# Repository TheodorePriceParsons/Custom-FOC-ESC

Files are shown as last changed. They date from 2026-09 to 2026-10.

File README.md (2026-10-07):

# Custom FOC ESC

Custom field-oriented-control motor controller.

## Structure
- `firmware/` — STM32G474 firmware (STM32CubeIDE project)
- `hardware/` — KiCad PCB design
- `mechanical/` — mounts and enclosure CAD

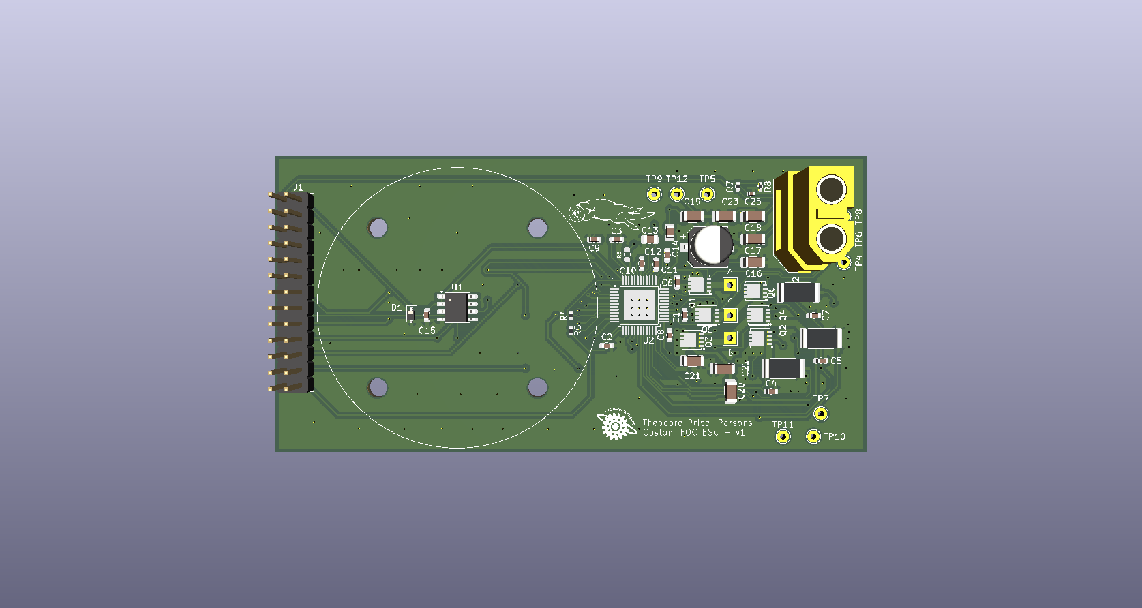
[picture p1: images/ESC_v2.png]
FOC ESC v2 — 3D render


### 1. Electrical angle

The MT6701 measures the mechanical angle $\theta_m$. The control math uses the electrical angle, which advances $p$ (number of pole pairs) times per mechanical revolution:

```math
\theta_e = p \, (\theta_m - \theta_0) \bmod 2\pi
```

$\theta_0$ is the encoder offset, found by running current through phase A and reading where the rotor settles.

### 2. Clarke transform: $(a, b, c) \rightarrow (\alpha, \beta)$

The three phase currents are 120° apart and sum to zero ($i_a + i_b + i_c = 0$), so only two of them carry independent information. The Clarke transform projects them onto two orthogonal stationary axes. The amplitude-invariant form keeps a phase current of amplitude $I$ as a vector of magnitude $I$:

```math
\begin{bmatrix} i_\alpha \\ i_\beta \end{bmatrix}
= \frac{2}{3}
\begin{bmatrix} 1 & -\tfrac{1}{2} & -\tfrac{1}{2} \\[2pt] 0 & \tfrac{\sqrt{3}}{2} & -\tfrac{\sqrt{3}}{2} \end{bmatrix}
\begin{bmatrix} i_a \\ i_b \\ i_c \end{bmatrix}
```

All three phase currents are used, in order to average shunt measurement noise.

### 3. Park transform: $(\alpha, \beta) \rightarrow (d, q)$

Rotating by $\theta_e$ moves into the rotor's reference frame. In steady state, the sinusoidal currents become **constants**:

```math
\begin{bmatrix} i_d \\ i_q \end{bmatrix}
=
\begin{bmatrix} \cos\theta_e & \sin\theta_e \\ -\sin\theta_e & \cos\theta_e \end{bmatrix}
\begin{bmatrix} i_\alpha \\ i_\beta \end{bmatrix}
```

- $i_d$: current aligned with the rotor magnets. It produces no torque and is regulated to 0.
- $i_q$: current perpendicular to the rotor magnets. Torque is $\tau = k_t i_q$.

The inverse Park transform is the transpose of the same rotation matrix:

```math
\begin{bmatrix} v_\alpha \\ v_\beta \end{bmatrix}
=
\begin{bmatrix} \cos\theta_e & -\sin\theta_e \\ \sin\theta_e & \cos\theta_e \end{bmatrix}
\begin{bmatrix} v_d \\ v_q \end{bmatrix}
```

### 4. Plant model

In the rotor frame, each axis is an RL circuit with coupling and back-EMF terms ($\omega_e$ = electrical speed, $\lambda$ = magnet flux linkage):

```math
v_d = R \, i_d + L \frac{di_d}{dt} - \omega_e L \, i_q
```

```math
v_q = R \, i_q + L \frac{di_q}{dt} + \omega_e L \, i_d + \omega_e \lambda
```

The $\omega_e$ terms vary slowly compared to the current loop, so they are treated as disturbances that the integrator rejects. Taking the Laplace transform with zero initial conditions gives the plant for each axis:

```math
G(s) = \frac{I(s)}{V(s)} = \frac{1}{Ls + R}
```

This is a single real pole at $s = -R/L$, i.e. the electrical time constant $\tau_e = L/R$.

### 5. PI current controller (continuous design)

```math
C(s) = K_p + \frac{K_i}{s} = K_p \, \frac{s + K_i/K_p}{s}
```

The open-loop transfer function is

```math
C(s) \, G(s) = \frac{K_p}{L} \cdot \frac{s + K_i/K_p}{s \, (s + R/L)}
```

Choose $K_i / K_p = R/L$ so that the controller zero cancels the plant pole (pole-zero cancellation, also called IMC tuning):

```math
C(s) \, G(s) = \frac{K_p}{L \, s}
\quad\Longrightarrow\quad
T(s) = \frac{C G}{1 + C G} = \frac{\omega_c}{s + \omega_c}, \qquad \omega_c = \frac{K_p}{L}
```

The closed loop is first-order with bandwidth $\omega_c$, so a step in the current reference produces no overshoot:

```math
i(t) = i_{ref} \left(1 - e^{-\omega_c t}\right)
```

```math
\boxed{K_p = \omega_c L, \qquad K_i = \omega_c R}
```

By the final value theorem, the integrator drives steady-state error to zero for a constant reference. This is why the control is done in the dq frame, where the references are DC.

**Choosing $\omega_c$.** The bandwidth must stay well below the loop rate $f_s$. A typical choice is $f_c \le f_s / 20$. If $R$ or $L$ is mismatched, the cancellation is imperfect, which causes mild overshoot or a slow tail. The loop stays stable for any positive gains.

**Measuring $L$.** Apply a voltage step $V$ to one phase pair. Taking the inverse Laplace transform of $V / (s(Ls+R))$ gives

```math
i(t) = \frac{V}{R} \left(1 - e^{-tR/L}\right)
```

so the time to reach 63.2% of the final current is $\tau_e = L/R$.

### 6. Discrete PI with anti-windup

The controller runs at a fixed period $T_s$. The integrator $1/s$ is discretized with forward Euler, $1/s \approx T_s/(z - 1)$:

```math
e[k] = i_{ref}[k] - i[k]
```

```math
v[k] = K_p \, e[k] + x[k]
```

```math
x[k+1] = x[k] + K_i T_s \, e[k]
```

The output voltage vector is limited by what the inverter can produce (see §7):

```math
\sqrt{v_d^2 + v_q^2} \le V_{max} = k_{max} \, \frac{V_{bus}}{\sqrt{3}}, \qquad k_{max} \approx 0.9
```

When the output saturates, the integrator update is skipped (conditional integration). This prevents windup at high speed, where back-EMF consumes the available voltage.

### 7. Space-vector modulation

The motor's star point floats, so it only responds to **differences** between phase voltages. Adding the same common-mode offset $v_{cm}$ to all three phases changes nothing the motor sees, but it can re-center the duties to use the full bus.

With inverse Clarke:

```math
v_a = v_\alpha, \qquad
v_b = -\tfrac{1}{2} v_\alpha + \tfrac{\sqrt{3}}{2} v_\beta, \qquad
v_c = -\tfrac{1}{2} v_\alpha - \tfrac{\sqrt{3}}{2} v_\beta
```

the common-mode offset is

```math
v_{cm} = \frac{\max(v_a, v_b, v_c) + \min(v_a, v_b, v_c)}{2}
```

and the duty for each phase $x \in$ {a, b, c} is

```math
d_x = \frac{1}{2} + \frac{v_x - v_{cm}}{V_{bus}}
```

This min/max injection is mathematically equivalent to symmetric (7-segment) SVPWM. It raises the maximum line-to-line voltage from $\sqrt{3}/2 \cdot V_{bus}$ (sine PWM) to $V_{bus}$, about 15.5% more, so the maximum phase-vector magnitude is $V_{bus}/\sqrt{3}$.

$k_{max} < 1$ keeps every phase low for part of each period, so the low-side shunt current can be sampled at the PWM center.

### 8. Parameters

| Symbol | Meaning | Value |
|---|---|---|
| $R$ | Phase resistance | TBD (measured) |
| $L$ | Phase inductance | TBD (step test) |
| $p$ | Pole pairs | TBD (count magnets / 2) |
| $\theta_0$ | Encoder offset | Calibrated at startup |
| $f_s$ | Control loop rate | ≈ 10.38 kHz |
| $f_c$ | Current loop bandwidth | TBD (≤ $f_s/20$) |
| $k_{max}$ | Modulation limit | 0.9 |

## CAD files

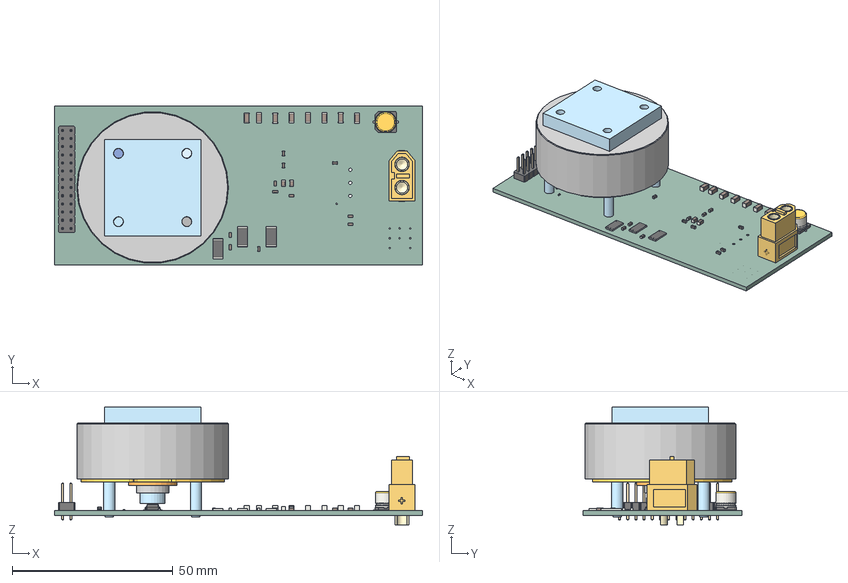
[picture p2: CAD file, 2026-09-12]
mechanical/Mounts.step
114.3 x 49.5 x 36.6 mm
Stator__Línea de partición1[12]
Stator__Línea de partición1[24]
Stator__Línea de partición1[1]
Rotor__Saliente-Extruir3[1]
Bearing__Simetría1
Stator__Línea de partición1[19]
Stator__Línea de partición1[4]
Rotor__Saliente-Extruir3[15]
Rotor__Rosca5
Stator__Línea de partición1[22]
Rotor__Saliente-Extruir3[16]
Nut__Cortar-Extruir1
Rotor__Saliente-Extruir3[6]
Rotor__Saliente-Extruir3[8]
Stator__Línea de partición1[17]
Rotor__Saliente-Extruir3[12]
Stator__Línea de partición1[14]
Stator__Línea de partición1[6]
Rotor__Saliente-Extruir3[21]
Rotor__Saliente-Extruir3[9]
Stator__Línea de partición1[7]
Stator__Línea de partición1[15]
Rotor__Saliente-Extruir3[14]
Rotor__Saliente-Extruir3[13]
Rotor__Saliente-Extruir3[2]
Rotor__Saliente-Extruir3[11]
Rotor__Saliente-Extruir3[5]
Stator__Redondeo5
Stator__Saliente-Extruir5
Stator__Línea de partición1[20]
Rotor__Saliente-Extruir3[20]
Stator__Línea de partición1[8]
Stator__Línea de partición1[10]
Rotor__Saliente-Extruir3[7]
Rotor__Saliente-Extruir3[19]
Stator__Línea de partición1[3]
Stator__Línea de partición1[9]
Rotor__Saliente-Extruir3[17]
Stator__Línea de partición1[11]
Stator__Línea de partición1[18]
Stator__Línea de partición1[16]
Rotor__Saliente-Extruir3[22]
Stator__Línea de partición1[5]
Stator__Línea de partición1[2]
Stator__Línea de partición1[23]
Rotor__Saliente-Extruir3[4]
Rotor__Saliente-Extruir3[10]
Rotor__Saliente-Extruir3[3]
Stator__Línea de partición1[13]
Rotor__Saliente-Extruir3[18]
Stator__Línea de partición1[21]
C_0603_1608Metric x 13
C_0805_2012Metric x 2
C_1206_3216Metric x 8
R_0402_1005Metric x 2
PinHeader_2x13_P254mm_Vertical
SO-8_3.9x4.9mm_P1.27mm
D_SOD-323
R_2512_6332Metric x 3
ESCC85C_PCB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

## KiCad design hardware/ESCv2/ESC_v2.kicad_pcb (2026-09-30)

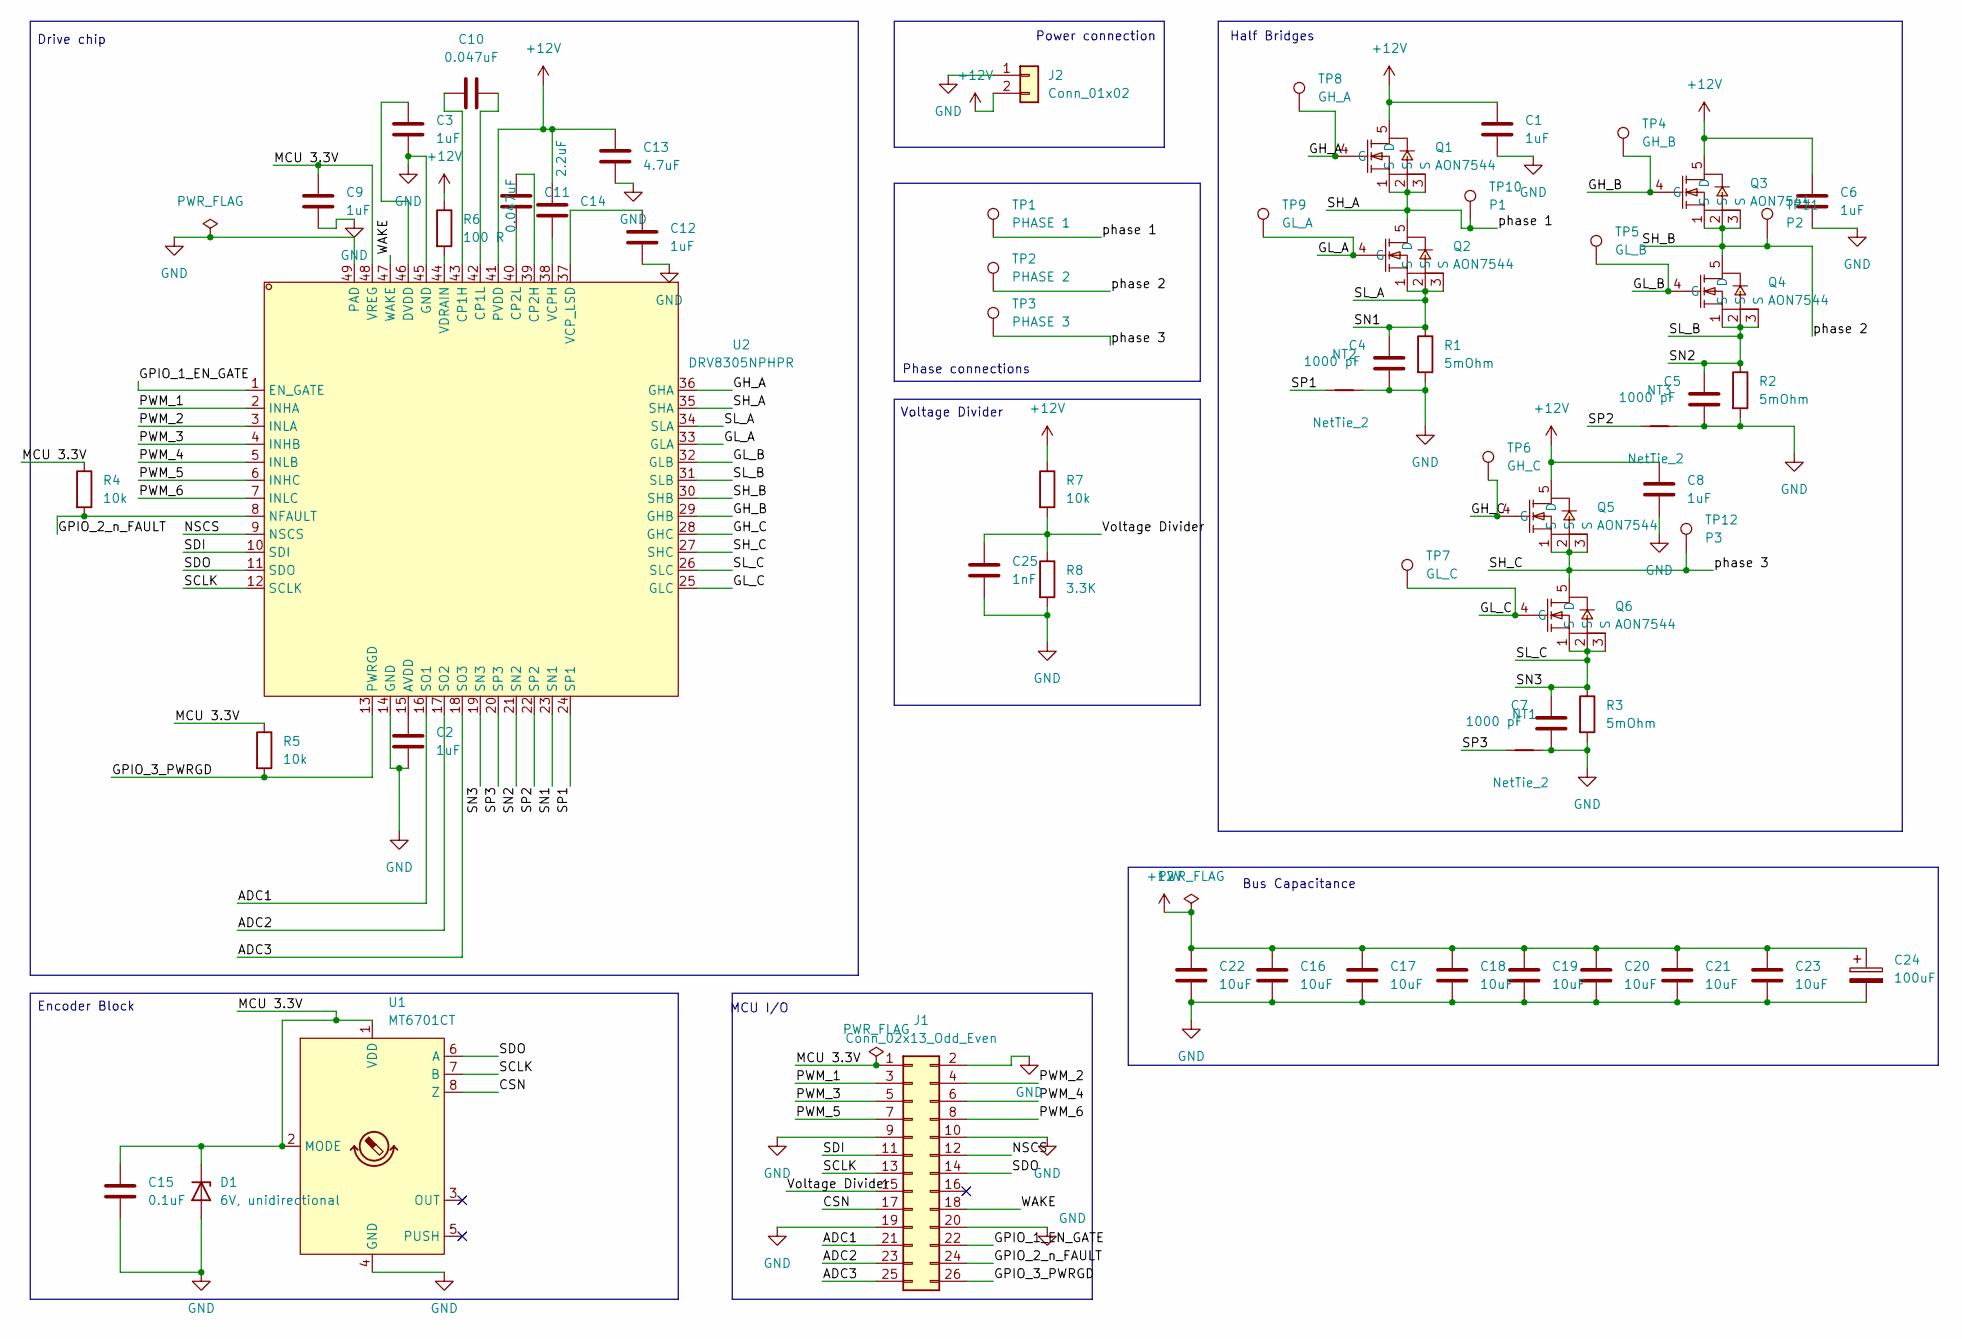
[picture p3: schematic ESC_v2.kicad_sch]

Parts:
C1, C2, C3, C6, C8, C9, C12: 1uF; C_0603_1608Metric; LCSC ID C29936
C4, C5, C7: 1000 pF; C_0603_1608Metric; LCSC ID C1588
C10, C11: 0.047uF; C_0603_1608Metric; LCSC ID C1622
C13: 4.7uF; C_0805_2012Metric; LCSC ID C1779
C14: 2.2uF; C_0805_2012Metric; LCSC ID C49217
C15: 0.1uF; C_0603_1608Metric; LCSC ID C14663
C16, C17, C18, C19, C20, C21, C22, C23: 10uF; C_1206_3216Metric; LCSC ID C89632
C24: 100uF; CP_Elec_6.3x5.9; LCSC ID C46550460
C25: 1nF; C_0402_1005Metric; LCSC ID C53547
D1: 6V, unidirectional; D_SOD-323; LCSC ID C7461
J1: Conn_02x13_Odd_Even; PinHeader_2x13_P2.54mm_Vertical
J2: Conn_01x02; AMASS_XT60-F_1x02_P7.20mm_Vertical
NT1, NT2, NT3: NetTie_2; NetTie-2_SMD_Pad0.5mm
Q1, Q2, Q3, Q4, Q5, Q6: AON7544; DFN-8_L3.3-W3.3-P0.65-BL-2; MPN AON7544; LCSC ID C315567
R1, R2, R3: 5mOhm; R_2512_6332Metric; LCSC ID C500739
R4, R5: 10k; R_0402_1005Metric; LCSC ID C25744
R6: 100 R; R_0603_1608Metric; LCSC ID C22775
R7: 10k; R_0402_1005Metric; LCSC ID C2889342
R8: 3.3K; R_0402_1005Metric; LCSC ID C2889356
TP1: PHASE 1; TestPoint_THTPad_2.0x2.0mm_Drill1.0mm
TP2: PHASE 2; TestPoint_THTPad_2.0x2.0mm_Drill1.0mm
TP3: PHASE 3; TestPoint_THTPad_2.0x2.0mm_Drill1.0mm
TP4: GH_B; TestPoint_THTPad_D2.0mm_Drill1.0mm
TP5: GL_B; TestPoint_THTPad_D2.0mm_Drill1.0mm
TP6: GH_C; TestPoint_THTPad_D2.0mm_Drill1.0mm
TP7: GL_C; TestPoint_THTPad_D2.0mm_Drill1.0mm
TP8: GH_A; TestPoint_THTPad_D2.0mm_Drill1.0mm
TP9: GL_A; TestPoint_THTPad_D2.0mm_Drill1.0mm
TP10: P1; TestPoint_THTPad_D2.0mm_Drill1.0mm
TP11: P2; TestPoint_THTPad_D2.0mm_Drill1.0mm
TP12: P3; TestPoint_THTPad_D2.0mm_Drill1.0mm
U1: MT6701CT; SO-8_3.9x4.9mm_P1.27mm; LCSC ID C2856764
U2: DRV8305NPHPR; HTQFP-48_L7.0-W7.0-P0.50-LS9.0-BL-EP5.1; MPN DRV8305NPHPR; LCSC ID C75602

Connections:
+12V: C1.1, C6.1, C8.1, C13.1, C14.1, C16.1, C17.1, C18.1, C19.1, C20.1, C21.1, C22.1, C23.1, C24.1, J2.2, Q1.5 (D), Q3.5 (D), Q5.5 (D), R6.1, R7.1, U2.41 (PVDD)
/ADC1: J1.21, U2.16 (SO1)
/ADC2: J1.23, U2.17 (SO2)
/ADC3: J1.25, U2.18 (SO3)
/CSN: J1.17, U1.8 (Z)
/GH_A: Q1.4 (G), TP8.1 (1_1), U2.36 (GHA)
/GH_B: Q3.4 (G), TP4.1 (1_1), U2.29 (GHB)
/GH_C: Q5.4 (G), TP6.1 (1_1), U2.28 (GHC)
/GL_A: Q2.4 (G), TP9.1 (1_1), U2.33 (GLA)
/GL_B: Q4.4 (G), TP5.1 (1_1), U2.32 (GLB)
/GL_C: Q6.4 (G), TP7.1 (1_1), U2.25 (GLC)
/GPIO_1_EN_GATE: J1.22, U2.1 (EN_GATE)
/GPIO_2_n_FAULT: J1.24, R4.2, U2.8 (NFAULT)
/GPIO_3_PWRGD: J1.26, R5.2, U2.13 (PWRGD)
/MCU 3.3V: C9.1, C15.1, D1.1 (K), J1.1, R4.1, R5.1, U1.1 (VDD), U1.2 (MODE), U2.48 (VREG)
/NSCS: J1.12, U2.9 (NSCS)
/PWM_1: J1.3, U2.2 (INHA)
/PWM_2: J1.4, U2.3 (INLA)
/PWM_3: J1.5, U2.4 (INHB)
/PWM_4: J1.6, U2.5 (INLB)
/PWM_5: J1.7, U2.6 (INHC)
/PWM_6: J1.8, U2.7 (INLC)
/SCLK: J1.13, U1.7 (B), U2.12 (SCLK)
/SDI: J1.11, U2.10 (SDI)
/SDO: J1.14, U1.6 (A), U2.11 (SDO)
/SH_A: Q1.1 (S), Q1.2 (S), Q1.3 (S), Q2.5 (D), TP1.1 (1_1), TP10.1 (1_1), U2.35 (SHA)
/SH_B: Q3.1 (S), Q3.2 (S), Q3.3 (S), Q4.5 (D), TP2.1 (1_1), TP11.1 (1_1), U2.30 (SHB)
/SH_C: Q5.1 (S), Q5.2 (S), Q5.3 (S), Q6.5 (D), TP3.1 (1_1), TP12.1 (1_1), U2.27 (SHC)
/SL_A: C4.1, Q2.1 (S), Q2.2 (S), Q2.3 (S), R1.1, U2.23 (SN1), U2.34 (SLA)
/SL_B: C5.1, Q4.1 (S), Q4.2 (S), Q4.3 (S), R2.1, U2.21 (SN2), U2.31 (SLB)
/SL_C: C7.1, Q6.1 (S), Q6.2 (S), Q6.3 (S), R3.1, U2.19 (SN3), U2.26 (SLC)
/SP1: NT2.1, U2.24 (SP1)
/SP2: NT3.1, U2.22 (SP2)
/SP3: NT1.1, U2.20 (SP3)
/Voltage Divider: C25.1, J1.15, R7.2, R8.1
/WAKE: J1.18, U2.47 (WAKE)
GND: C1.2, C2.2, C3.2, C4.2, C5.2, C6.2, C7.2, C8.2, C9.2, C12.2, C13.2, C15.2, C16.2, C17.2, C18.2, C19.2, C20.2, C21.2, C22.2, C23.2, C24.2, C25.2, D1.2 (A), J1.2, J1.9, J1.10, J1.19, J1.20, J2.1, NT1.2, NT2.2, NT3.2, R1.2, R2.2, R3.2, R8.2, U1.4 (GND), U2.14 (GND), U2.45 (GND), U2.49 (PAD)
unnamed: C2.1, U2.15 (AVDD)
unnamed: C10.1, U2.43 (CP1H)
unnamed: C10.2, U2.42 (CP1L)
unnamed: C11.2, U2.39 (CP2H)
unnamed: C11.1, U2.40 (CP2L)
unnamed: C3.1, U2.46 (DVDD)
unnamed: C14.2, U2.38 (VCPH)
unnamed: C12.1, U2.37 (VCP_LSD)
unnamed: R6.2, U2.44 (VDRAIN)

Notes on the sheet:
Voltage Divider
MCU I/O
Phase connections
Encoder Block
Bus Capacitance
Drive chip
Half Bridges
Power connection

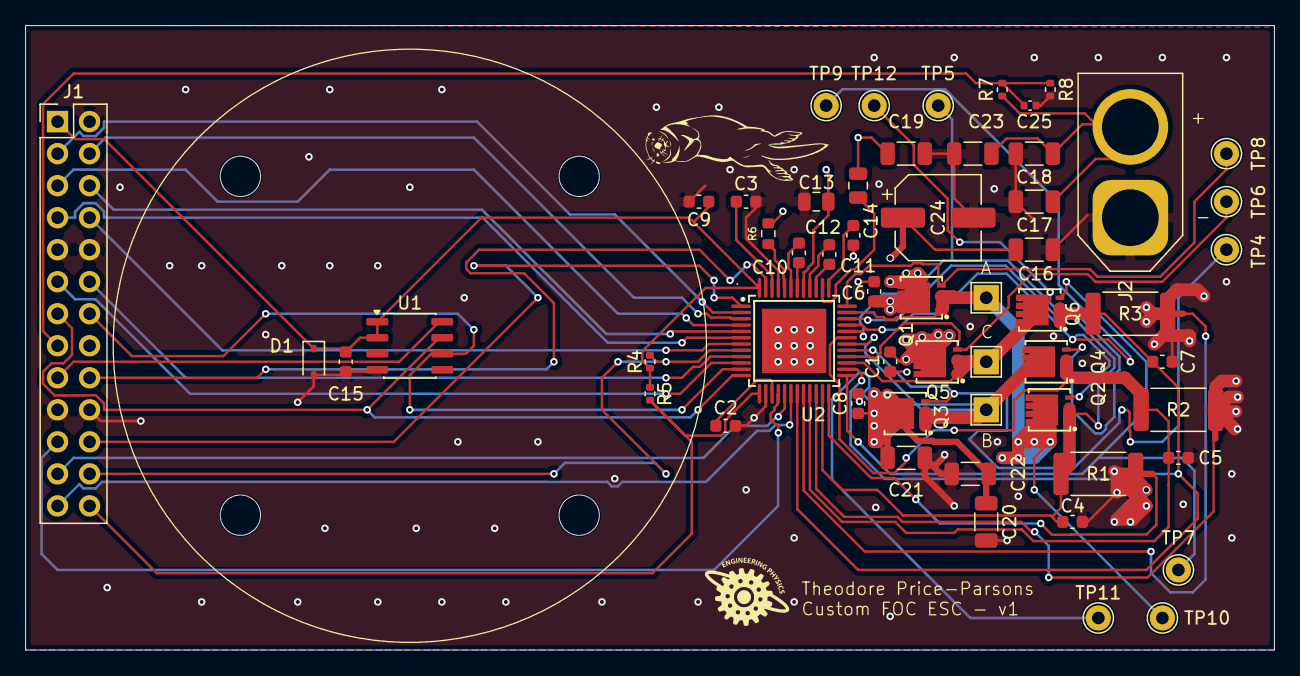
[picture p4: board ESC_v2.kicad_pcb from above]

Board: 4 copper layers, 99.1 x 49.5 mm, 59 parts (0 on the bottom side), 46 nets.

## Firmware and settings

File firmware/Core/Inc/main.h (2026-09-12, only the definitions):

#define RCC_OSC32_IN_Pin GPIO_PIN_14
#define RCC_OSC32_IN_GPIO_Port GPIOC
#define RCC_OSC32_OUT_Pin GPIO_PIN_15
#define RCC_OSC32_OUT_GPIO_Port GPIOC
#define RCC_OSC_IN_Pin GPIO_PIN_0
#define RCC_OSC_IN_GPIO_Port GPIOF
#define RCC_OSC_OUT_Pin GPIO_PIN_1
#define RCC_OSC_OUT_GPIO_Port GPIOF
#define DRV_CS_Pin GPIO_PIN_8
#define DRV_CS_GPIO_Port GPIOC
#define MT_CS_Pin GPIO_PIN_9
#define MT_CS_GPIO_Port GPIOC
#define TIMING_OUT_Pin GPIO_PIN_9
#define TIMING_OUT_GPIO_Port GPIOA
#define T_SWDIO_Pin GPIO_PIN_13
#define T_SWDIO_GPIO_Port GPIOA
#define T_SWCLK_Pin GPIO_PIN_14
#define T_SWCLK_GPIO_Port GPIOA
#define T_SWO_Pin GPIO_PIN_3
#define T_SWO_GPIO_Port GPIOB

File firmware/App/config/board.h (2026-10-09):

/*
 * board.h
 *
 *  Created on: Oct 8, 2026
 *      Author: theop
 */

#ifndef CONFIG_BOARD_H_
#define CONFIG_BOARD_H_

//timing
#define PWM_PERIOD      65527.0f
#define PWM_DUTY_MIN    0.001f
#define PWM_DUTY_MAX    0.95f

#define F_LOOP          10377.0f
#define DT              (1.0f / F_LOOP)

//ADC
#define ADC_VREF        3.3f
#define ADC_MAX         4096.0f

//Current sense
#define R_SHUNT         0.005f
#define CSA_GAIN        40.0f
#define AMPS_PER_COUNT  (ADC_VREF / (ADC_MAX * CSA_GAIN * R_SHUNT))
#define I_SENSE_MAX     ((ADC_VREF / 2.0f) / (CSA_GAIN * R_SHUNT))

//Bus divider
#define VBUS_R_TOP      10000.0f
#define VBUS_R_BOT      3300.0f
#define VOLTS_PER_COUNT ((ADC_VREF / ADC_MAX) * (VBUS_R_TOP + VBUS_R_BOT) / VBUS_R_BOT)

//MT encoder
#define ENC_COUNTS      16384.0f



#endif

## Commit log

2026-09-12 initial commit: firmware(compiling), hardware(done), mechanical(done)
    [ESC.kicad_pcb, Mounts.step]
2026-09-12 Add missing schematic
    [ESC.kicad_sch]
2026-09-15 updated SPI communication with DRV and MT
2026-09-22 improved PCB v2
    [ESC.kicad_pcb, ESC.kicad_sch, ESC_v2.kicad_pcb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]
2026-09-23 relocating shunts closer to FETs
    [ESC_v2.kicad_pcb]
2026-09-28 improved Kelvin shunts
    [ESC_v2.kicad_pcb, ESC_v2.kicad_sch]
2026-09-30 Improved kelvin shunts (for real this time), bootstrap caps closer to the DRV chip, added GND pour and a beautiful otter for good luck
    [ESC_v2.kicad_pcb, ESC_v2.kicad_sch]
2026-10-22 fixed SPI communication, mag encoder tried and tested and hardware is fully functional. Motor Spinning unevenly at times
2026-10-23 final PCB version added
2026-10-27 after running a few bench tests, current loop is fine, SSI timing seems fine but suspected lopsided magnet causing speed ripple

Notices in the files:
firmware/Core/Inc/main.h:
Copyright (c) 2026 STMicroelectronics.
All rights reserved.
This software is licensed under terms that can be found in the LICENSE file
